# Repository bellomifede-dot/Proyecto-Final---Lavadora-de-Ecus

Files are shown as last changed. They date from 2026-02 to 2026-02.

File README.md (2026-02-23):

# Proyecto SCARA + Lavadora de ECUs

**Célula automatizada para la limpieza y manejo de Unidades de Control Electrónico (ECU)**

Este proyecto desarrolla una célula automatizada capaz de localizar, manipular y limpiar placas electrónicas (ECUs) mediante un robot SCARA y una unidad de lavado. El sistema busca reducir la intervención manual, homogeneizar el proceso y mejorar la trazabilidad de las piezas sometidas a mantenimiento o preparación previa a ensayos. 

<p align="center">
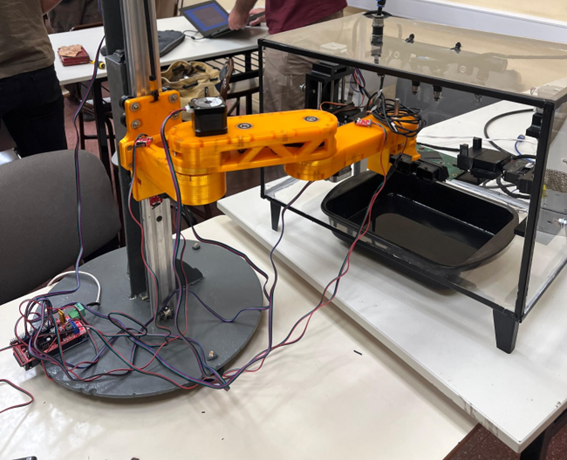
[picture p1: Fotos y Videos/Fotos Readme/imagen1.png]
Placa ECU - vista
  
</p>

---
## Tabla de contenidos
- [Descripción](#descripción)
- [Objetivos](#objetivos)
- [Funcionamiento general](#funcionamiento-general)
- [Componentes principales](#componentes-principales)
---

## Descripción
El sistema consiste en una mesa de entrada donde se colocan las placas sucias, un subsistema de visión que localiza cada placa, un robot SCARA que las recoge y entrega a una caja de lavado. La caja realiza dos etapas: un rociado dirigido (para despegar suciedad superficial) y una inmersión demostrativa en una bandeja. Al finalizar, la placa se devuelve al punto de salida lista para inspección o uso. 

## Objetivos
- Automatizar la manipulación y limpieza de ECUs.
- Minimizar el manejo manual y la exposición del operario a solventes.
- Homogeneizar el proceso para asegurar repetibilidad y trazabilidad.
- Proveer una base técnica y documental para reproducir o adaptar la célula en otros entornos.

## Funcionamiento general
1. **Detección**: la cámara ubica las placas en la mesa mediante algoritmos de visión por computador.  
2. **Clasificación / Etiquetado (opcional)**: identificación del tipo de ECU y registro.  
3. **Agarre y transporte**: el robot SCARA toma la placa y la coloca en la estación de lavado.  
4. **Lavado en dos etapas**:
   - Rociado dirigido (elimina suciedad superficial).
   - Inmersión demostrativa en bandeja de limpieza.  
5. **Devolución**: la placa vuelve al puesto de salida para inspección y trazabilidad.

## Componentes principales
- **Robot SCARA** — para recogida y manipulación precisa.  
- **Subsistema de visión** — detección y posicionamiento.  
- **Caja de lavado** — sistema de rociado + inmersión.  
- **Controlador / PC maestro** — coordina visión, robot y secuencia de lavado.  
- **ECUs** — piezas a limpiar; sensibles a humedad/solventes y por tanto se deben seguir consideraciones de seguridad.

<p align="center">
  <a href="https://youtu.be/JoXS6hfcZ1g" target="_blank" rel="noopener noreferrer">
    Demo - Lavadora de ECUs
  </a>
</p>

<p align="center"><em>Ver demo: Lavadora de ECUs</em></p>

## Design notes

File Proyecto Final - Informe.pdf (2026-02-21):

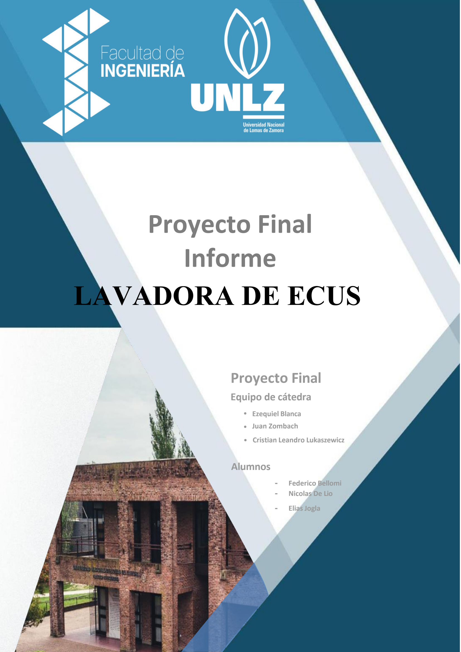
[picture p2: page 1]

Universidad Nacional de Lomas de Zamora

Facultad de Ingeniería

1

# Proyecto Final Informe

# LAVADORA DE ECUS

# Proyecto Final

## Equipo de cátedra

- Ezequiel Blanca
- Juan Zombach
- Cristian Leandro Lukaszewicz

## Alumnos

- Federico Bellomi
- Nicolas De Lio
- EliasJogla

Contenido

### 4. Diseño mecánico del Robot SCARA — (fase de diseño: cálculos previsionales)16

4.13 Fijación de la última polea al siguiente segmento (interfaz de transmisión entre segmentos)

La PC actúa como maestro: toma decisiones de alto nivel (qué pieza procesar, cuándo iniciar

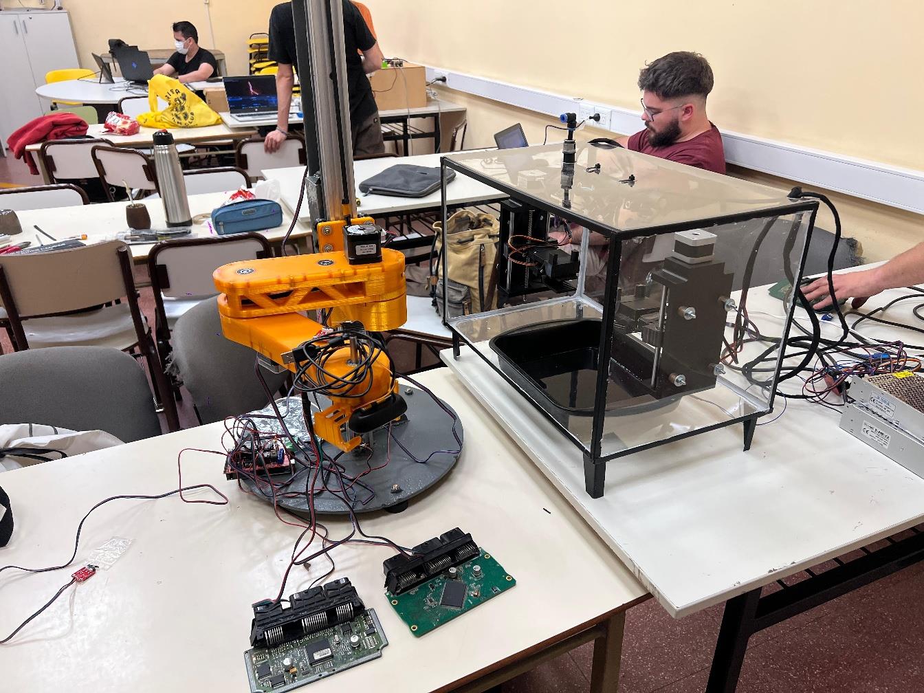
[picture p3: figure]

### 1. Introducción

En el ámbito de la electrónica automotriz moderna, las Unidades de Control Electrónico (ECU, Electronic Control Unit) cumplen un rol fundamental en la gestión de los sistemas del vehículo, tales como la inyección de combustible, encendido, control de emisiones y monitoreo de sensores críticos. Estas unidades están compuestas por placas electrónicas de alta densidad, con componentes sensibles a factores ambientales como la humedad, el polvo, residuos químicos y contaminantes atmosféricos.

Uno de los problemas más frecuentes en el sector de reparación electrónica automotriz es el deterioro progresivo de las ECUs debido a la acumulación de suciedad y a la presencia de humedad. Esta situación puede generar desde fallas intermitentes hasta la inutilización completa del sistema, provocando pérdidas económicas significativas y tiempos prolongados de diagnóstico y reparación. Los métodos de limpieza actualmente utilizados (principalmente el cepillado manual con alcohol isopropílico y el lavado por ultrasonido convencional) presentan limitaciones en términos de repetibilidad, eficiencia, estandarización y seguridad del proceso.

En este contexto, surge la necesidad de desarrollar una solución automatizada que permita mejorar la calidad del proceso de limpieza, reducir la intervención humana y aumentar la confiabilidad del procedimiento. El presente proyecto propone el diseño y desarrollo de una célula automatizada compuesta por un robot tipo SCARA y una lavadora de ECUs de doble etapa (aspersión controlada y limpieza ultrasónica), integrada con un sistema de visión artificial basado en inteligencia artificial para la detección y localización automática de las placas electrónicas.

La solución desarrollada contempla no solo la automatización del proceso de limpieza, sino también la integración coordinada entre los subsistemas mecánicos, electrónicos y de control, garantizando precisión en la manipulación, repetibilidad en los movimientos y seguridad en la operación. El robot SCARA se encarga de la manipulación de las placas mediante un sistema pick and place, mientras que la lavadora ejecuta el ciclo de limpieza de manera autónoma. El sistema de visión permite identificar la posición de las ECUs en el área de trabajo, transformando la información visual en coordenadas utilizables por el robot.

El desarrollo del proyecto implicó el diseño mecánico estructural del robot, el dimensionamiento de motores y fuentes de alimentación, el análisis de esfuerzos y torques, el diseño electrónico de potencia y control, la programación del microcontrolador, la implementación de algoritmos de cinemática inversa y la integración con un sistema de procesamiento de imágenes en una computadora externa.
El presente informe describe de manera detallada el proceso de diseño, cálculo, implementación y validación del sistema completo, incluyendo los análisis mecánicos y electrónicos correspondientes, la planificación del proyecto, la evaluación económica y los ensayos realizados para verificar el cumplimiento de los objetivos establecidos.

### 1.1 Contexto del problema

La evolución de la industria automotriz ha incrementado significativamente la cantidad y complejidad de sistemas electrónicos presentes en los vehículos modernos. Las Unidades de Control Electrónico (ECUs) son responsables de procesar señales provenientes de múltiples sensores y ejecutar estrategias de control en tiempo real, convirtiéndose en elementos críticos para el correcto funcionamiento del vehículo. Debido a su ubicación dentro del compartimiento del motor o en zonas expuestas a condiciones adversas, las ECUs se encuentran sometidas a variaciones térmicas, vibraciones mecánicas, humedad ambiental y posibles filtraciones de líquidos. Con el paso del tiempo, estas condiciones pueden generar acumulación de suciedad, corrosión en pistas conductoras y degradación de contactos eléctricos, afectando el desempeño del sistema.

En el ámbito de la reparación electrónica automotriz, la limpieza de estas placas constituye una etapa previa fundamental antes de realizar diagnósticos o intervenciones más profundas. Sin embargo, los procedimientos actuales presentan limitaciones importantes. La limpieza manual mediante cepillado y solventes depende en gran medida de la habilidad del operario, carece de repetibilidad y puede resultar insuficiente para remover contaminantes en zonas de difícil acceso. Por otro lado, los sistemas de lavado ultrasónico disponibles comercialmente no siempre están integrados dentro de un proceso automatizado que contemple manipulación, posicionamiento y control del flujo de trabajo.

Esta situación evidencia una oportunidad de mejora mediante la implementación de soluciones automatizadas que integren tecnologías de manipulación robótica, limpieza controlada y visión artificial, permitiendo estandarizar el proceso, aumentar la eficiencia y reducir la intervención humana directa.

### 1.2 Justificación técnica

El desarrollo de una célula automatizada para la limpieza de ECUs se justifica desde múltiples perspectivas técnicas y operativas. En primer lugar, la automatización del proceso permite garantizar condiciones de operación repetibles y controladas, reduciendo la variabilidad asociada al trabajo manual. Esto resulta especialmente relevante en tareas donde la precisión y el cuidado del componente son fundamentales para evitar daños adicionales.

Desde el punto de vista mecánico, la incorporación de un robot tipo SCARA ofrece ventajas significativas en aplicaciones de manipulación plana, debido a su estructura rígida en el eje vertical y su alta velocidad en movimientos en el plano XY. Estas características lo convierten en una solución adecuada para operaciones de tipo pick and place, como la carga y descarga de placas electrónicas en la lavadora.

En el aspecto electrónico y de control, el diseño integral del sistema permite dimensionar adecuadamente fuentes de alimentación, drivers de motores y protecciones eléctricas, asegurando un funcionamiento seguro y eficiente. Asimismo, la implementación de cinemática inversa y secuencias de homing contribuye a mejorar la precisión y confiabilidad del robot.

Por otra parte, la incorporación de un sistema de visión artificial basado en inteligencia artificial permite automatizar la detección y localización de las placas dentro del área de trabajo, eliminando la necesidad de posicionamiento manual previo y aumentando el grado de autonomía del sistema.

Finalmente, desde una perspectiva académica y de ingeniería, el proyecto integra conocimientos de diseño mecánico, electrónica de potencia, control, programación, procesamiento de imágenes e integración de sistemas, constituyendo una aplicación multidisciplinaria que refleja las competencias adquiridas durante la carrera de Ingeniería Mecatrónica.

### 1.3 Objetivo general

Diseñar, desarrollar e integrar una célula automatizada compuesta por un robot tipo SCARA, una lavadora de ECUs de doble etapa (aspersión controlada y limpieza ultrasónica) y un sistema de visión artificial basado en inteligencia artificial, con el propósito de optimizar el proceso de limpieza de placas electrónicas automotrices, garantizando precisión, repetibilidad, seguridad y reducción de la intervención humana.

### 1.4 Objetivos específicos

Para alcanzar el objetivo general planteado, se establecen los siguientes objetivos específicos:

- Diseñar y construir un robot tipo SCARA capaz de realizar movimientos en el plano XY con un eje vertical Z, logrando una repetibilidad mínima de 1 mm y capacidad de manipulación de cargas de al menos 100 g.
- Implementar el modelado matemático del robot, incluyendo el desarrollo de la cinemática directa e inversa, para permitir el posicionamiento preciso del efector final.
- Diseñar un sistema de gripper adecuado para la sujeción segura de placas electrónicas, considerando su geometría y fragilidad.
- Desarrollar una lavadora de ECUs que integre un sistema de aspersión controlada mediante alcohol isopropílico y un sistema de limpieza ultrasónica, garantizando la eliminación de contaminantes superficiales y profundos.
- Dimensionar y diseñar el sistema electrónico completo, incluyendo selección de motores, drivers, fuentes de alimentación, sensores de fin de carrera y protecciones eléctricas, realizando los cálculos correspondientes de corriente, potencia y disipación térmica.
- Implementar un sistema de visión artificial capaz de detectar y localizar automáticamente las placas electrónicas dentro del área de trabajo, utilizando un modelo de inteligencia artificial ejecutado en una computadora externa.
- Desarrollar la comunicación entre la PC y el microcontrolador del robot, permitiendo la transferencia de coordenadas procesadas por el sistema de visión.
- Integrar todos los subsistemas mecánicos, electrónicos y de control en una arquitectura coordinada que permita un funcionamiento autónomo del proceso completo.
- Realizar ensayos de validación para verificar el cumplimiento de los requisitos de repetibilidad, carga, limpieza e integración del sistema.

### 2. Marco teórico

### 2.1 Limpieza de placas electrónicas

2.1.1 Métodos tradicionales
La limpieza de placas electrónicas se realiza habitualmente mediante tres enfoques: limpieza manual con solventes, aspersión controlada y ultrasonido. La limpieza manual con alcohol isopropílico u otros disolventes es económica y efectiva para contaminantes superficiales, pero depende altamente de la pericia del operador y carece de reproducibilidad. La aspersión controlada aplica energía mecánica puntual mediante chorros de fluido para desalojar residuos adheridos, siendo una alternativa intermedia entre el tratamiento manual y la inmersión completa. La limpieza por ultrasonido actúa a escala microscópica por cavitación, permitiendo la remoción en zonas inaccesibles para las técnicas anteriores; requiere control de frecuencia, potencia y temperatura del baño.

Cada técnica tiene ventajas y limitaciones en términos de agresividad, compatibilidad con componentes, seguridad (especialmente si se emplean solventes inflamables) y repetibilidad. Para procesos industriales y estandarizados se recomiendan soluciones automatizadas que combinen etapas complementarias (por ejemplo, aspersión seguida de ultrasonido) para maximizar eficacia sin dañar los componentes.

2.1.2 Limpieza por aspersión (aplicación al prototipo)
La etapa de aspersión en el sistema propuesto utiliza inyectores de combustión montados en posición fija y una bomba con presión operativa entre 2.7 y 4.1 bar, rango típico de bombas de inyectores y suficiente para generar chorros con alta energía cinética. Los parámetros operativos relevantes que condicionan la eficacia son: presión de trabajo, caudal, diámetro y geometría de la tobera, distancia nozzle–superficie, ángulo de incidencia y tiempo de exposición.

En la práctica del prototipo, la pieza (ECU) se somete a un ciclo de rotación que expone sucesivamente cara superior e inferior a los chorros. Esta estrategia permite que boquillas fijas cubran ambas caras sin necesidad de mecanismos articulados adicionales para las boquillas, reduciendo complejidad mecánica y puntos de fallo.

2.1.3 Limpieza por ultrasonido (principios y estado del prototipo)
La limpieza por ultrasonido convierte energía eléctrica en ondas mecánicas en el líquido mediante transductores; las oscilaciones inducen cavitación y el colapso de microburbujas genera micro chorros que desprenden contaminantes. Los parámetros críticos son la frecuencia (normalmente 20–400 kHz), la potencia específica (W/L), el tiempo de exposición y la temperatura del baño. Frecuencias bajas (20–40 kHz) favorecen cavitación intensa para suciedad gruesa; frecuencias altas (≥100 kHz) producen limpieza más fina y suave.

En el prototipo actual existe una batea y un motor desbalanceado que, en su configuración, sirve como demostrador mecánico, pero no logra la excitación a frecuencias ultrasónicas efectivas. La implementación plena del ultrasonido requiere transductores piezoeléctricos y drivers apropiados. Además, el uso de ultrasonido en presencia de solventes inflamables requiere equipamiento certificado (ATEX u homologaciones equivalentes), ventilación y control térmico.

### 2.2 Robots SCARA

2.2.1 Arquitectura y propiedades esenciales
Un robot tipo SCARA (Selective Compliance Assembly Robot Arm) es un manipulador caracterizado por articulaciones rotacionales en el plano XY y un grado de libertad prismático o rotacional en el eje Z. Su rigidez en la dirección vertical, la alta velocidad y la precisión en el plano horizontal lo hacen especialmente apto para tareas de pick & place, inserción y manipulación de piezas planas. Para la manipulación de ECUs (componentes relativamente planos y frágiles) el SCARA combina buena velocidad de ciclo con suficiente rigidez y repetibilidad.

2.2.2 Selección para la aplicación de limpieza de ECUs
La elección del SCARA se fundamenta en la necesidad de integrar un sistema de manipulación que realice carga/descarga, posicionamiento frente a boquillas de aspersión y colocación en la batea ultrasónica, todo con mínimo contacto humano. Se valora además la posibilidad de integrar un efector con cámara (eye-in-hand) para detección y sujeción precisa.

### 2.3 Cinemática de robots SCARA

2.3.1 Notación y parámetros geométricos del prototipo
Denotamos L1 y L2 las longitudes de los dos eslabones en el plano XY; en el prototipo L1=160 y L2=200m. Las variables articulares son θ1 (theta 1) y θ2 (theta 2) que son rotaciones en las uniones base → eslabón 1 y eslabón 1 → eslabón 2) y z para el eje prismático.

2.3.2 Cinemática directa
Las expresiones de la cinemática directa permiten calcular la posición cartesiana (x,y,z) del efector en función de los ángulos articulares:

x = L1 cos(θ1

) + L2 cos (θ1 + θ2)
y = L1 sin(θ1

) + L2 sin (θ1 + θ2)
z = z

Estas relaciones son la base para establecer la transformación entre espacio articular y espacio cartesiano usada por el planificador del robot.

2.3.3 Cinemática inversa
Dada la posición (x,y) deseada del efector, la obtención de θ1 y θ2 se realiza mediante:

r

2 = x

2 + y

2
; cos(θ2

) =

r

2 − L1

2 − L2

2
2L1

2L2

2

;

y
θ2 = atan2 (±√1 − cos²(θ2
) , cos(θ2

))
θ1 = atan2(y, x) − atan2(L2 sin(θ2

) , L1 + L2cos (θ2))

La solución presenta ambigüedad de configuración (dos soluciones—elbow-up/elbow-down) que debe resolverse con criterios basados en límites mecánicos, obstáculos y eficiencia de la trayectoria.

2.3.4 Jacobiano y control de velocidad
El Jacobiano J(θ) relaciona velocidades articulares θ˙ con velocidades cartesianas p˙=[x˙ y˙]T mediante p˙=J(θ). La inversa del Jacobiano (cuando existe) se usa para convertir velocidades cartesianas deseadas en velocidades articulares necesarias. El determinante de J indica singularidades donde la manipulación es problemática; por tanto es esencial planificar trayectorias evitando configuraciones cercanas a dichas singularidades.

2.3.5 Workspace y limitaciones prácticas
El workspace teórico del SCARA en el plano XY viene dado por el conjunto de radios r tales que ∣L1−L2∣ ≤ r ≤ L1+L2 . En la práctica, las limitaciones mecánicas (topes físicos, interferencias de estructura, rango del efector, espacio de montaje) reducen el workspace útil. Adicionalmente, la interacción con el sistema de visión y la disposición de la lavadora fijan zonas operativas preferentes.

### 2.4 Sistemas de visión artificial

2.4.1 Objetivo funcional en el sistema
El sistema de visión tiene por objetivo detectar la presencia y estimar la pose (posición y orientación plana) de las ECUs sobre la mesa de trabajo para proporcionar coordenadas que el controlador del robot utilice para el pick & place. La solución en el prototipo combina detección por redes convolucionales y marcadores QR para robustez y precisión.

2.4.2 Pipeline de procesamiento propuesto

El flujo típico se compone de:

1. Adquisición: la cámara montada en el efector (eye-in-hand) captura imágenes. En el prototipo se usa una cámara comercial de consumo (Logitech C270 HD 720p), adecuada para demostración; su obturador y tasa de frames deben ser consideradas al programar movimientos.
2. Preprocesado: corrección de distorsión, filtrado y normalización del histograma para robustecer la detección ante variaciones de iluminación.
3. Detección/segmentación: empleo de un detector de objetos basado en CNN (por ejemplo YOLO u arquitecturas análogas) para obtener cajas delimitadoras y puntos claves.
4. Estimación de pose: uso de marcadores QR (uno fijo como referencia y uno variable en cada ECU) para obtener la transformación relativa ECU→referencia; concebir la estimación mediante homografía si el plano es conocido o mediante PnP en caso de tener referencias 3D.
5. Transformación a coordenadas del robot: mediante calibración hand–eye convertir la pose en coordenadas del robot y enviar comandos de posicionamiento.

2.4.3 Calibración cámara–robot y conversión píxel→mundo
Se distinguen dos calibraciones necesarias:
- Calibración intrínseca: determina parámetros de la cámara (fx, fy, cx, cy) coeficientes de distorsión radial/tangencial. Se obtiene típicamente con patrones planos (tablero de ajedrez) y librerías como OpenCV.
- Calibración extrínseca / hand–eye: define la transformación rígida entre la cámara y la herramienta (efector). En configuraciones eye-in-hand es indispensable para traducir observaciones de la cámara a movimientos del robot

con precisión.

Si la cámara observa esencialmente un plano de trabajo fijo y la altura no varía significativamente, una homografía 2D proporciona una conversión eficaz entre coordenadas de imagen y coordenadas del plano. En casos más generales será necesario estimar la pose 3D usando solvePnP y la transformación hand–eye.

### 2.5 Microcontroladores y control de motores paso a paso

2.5.1 Plataforma de control y arquitectura electrónica

La electrónica de control del prototipo se basa en un microcontrolador de arquitectura compatible con proyectos de control de múltiples motores (se utiliza la placa Arduino Mega sobre la que se monta una shield tipo RAMPS 1.4 para alojar drivers de potencia). Esta configuración facilita la integración de drivers tipo DRV8825, sensores I²C (multiplexor TCA9548A y AS5600) y finales de carrera.

2.5.2 Principios de motores paso a paso y dimensionamiento aplicado
Los motores paso a paso se caracterizan por su paso por revolución (200 pasos = 1,8°), torque de retención y curva de torque a velocidad. En el proyecto se emplean NEMA17 de alto torque con especificación nominal 4.3 kg·cm (≈ 0.4217 N·m) y un NEMA17 pancake para J6 con 1.6 kg·cm (≈ 0.1569 N·m).

Efecto de la reducción: las transmisiones implantadas (relación compuesta 16:1 en J1/J2 y 1:5 en J6) multiplican el torque disponible en la salida de la transmisión, mientras que disminuyen la velocidad y aumentan la resolución angular por paso. Aplicando la reducción 16:1 al motor de 0.4217 N·m, el torque teórico disponible en el eje de salida es ≈ 6.747 N·m, una magnitud que excede holgadamente la demanda gravitatoria de una ECU de 0.1 kg colocada a r = 0.36 m (τ ≈ 0.353 N·m). Para dimensionamiento dinámico se debe incluir el término de inercia I y la aceleración angular requerida:

α: τ = Iα + τgravedad + τfricción

2.5.3 Drivers de etapa de potencia y ajustes térmicos

Los DRV8825 regulan corriente mediante control por chopper y requieren ajuste del límite de corriente acorde al motor. La disipación térmica es significativa; es imprescindible disipadores y ventilación forzada. Ajustar la corriente máxima evita sobrecalentamiento de los drivers y limita la corriente RMS en los motores.

2.5.4 Dimensionamiento de la fuente de alimentación (cálculo aplicado)

Con los consumos nominales aportados se calcula:
- Motores: 3 × NEMA17 alto-torque a 1.7 A/fase (3×1.7 = 5.1 A) y 1 × pancake a 1.0 A → total motores = 6.1 A.
- Aplicando margen de seguridad del 30%: corriente de diseño ≈ 7.93 A.
- Potencia requerida a 12 V: P=12 V×7.93 A≈95.2

La elección de una fuente 12 V / 15 A ofrece margen suficiente para picos de corriente y expansión futura. El circuito de control (Arduino, multiplexor I²C, sensores y drivers de lógica) se alimenta desde USB de la PC; el consumo estimado total de la electrónica de control es ≈ 174 mA (con margen operativo tomado a 250 mA).

### 3. Descripción general del sistema

### 3.1 Visión general y propósito

La célula automatizada integra un manipulador tipo SCARA, una lavadora de ECUs de doble etapa (aspersión y batea) y un sistema de visión montado en el efector del robot. El objetivo es automatizar la carga, limpieza y descarga de placas electrónicas automotrices con repetibilidad y mínima intervención humana. Las ECUs que se procesan disponen previamente de una pieza adaptadora impresa en 3D que incorpora un marcador QR y ranuras autocentrantes para el gripper del robot, estandarizando la sujeción y la referencia visual.

### 3.2 Arquitectura funcional (diagrama lógico — descripción)

La arquitectura se organiza en cuatro subsistemas principales:
- Operador / bandeja inicial. El operario inserta la pata 3D en la ECU y deja las piezas en la mesa de trabajo dentro del alcance del SCARA.
- Visión y procesamiento (PC). La cámara del efector captura imágenes; la PC ejecuta el detector y el módulo de IA para localizar QRs y calcular poses. (Se utiliza una cámara comercial Logitech C270 para la etapa de demostración). Logitech
- Control SCARA. Control local del manipulador (motor drivers, encoders, firmware) basado en una placa Arduino Mega con shield RAMPS 1.4. Arduino
- Lavadora (control local). Control independiente basado en otro Arduino Mega que gestiona bombas, servos, guías lineales y la batea; la comunicación simple entre SCARA y lavadora se realiza vía ESP32 para señales de evento.

El flujo de información es: PC (visión) → Control maestro → Control SCARA → (ESP32) → Control Lavadora, con señales de estado de retorno desde la lavadora hacia el maestro.

### 3.3 Flujo operativo (secuencia funcional, paso a paso)

1. Preparación: el operario instala la pata 3D en cada ECU y las deja sobre la mesa.
2. Inicio: el operario pulsa “Play” en la interfaz de la PC para iniciar la rutina.
3. Escaneo: el SCARA recorre posiciones de escaneo; la cámara captura imágenes y la PC detecta QRs.
4. Selección: al detectar un QR válido, la PC manda la pose al SCARA.
5. Pick: el SCARA va a la posición de captura, activa el gripper y toma la pieza (la geometría autocentrante asegura sujeción con tolerancia).
6. Transferencia: el SCARA lleva la pieza a la zona de entrega de la lavadora y deposita la ECU en la posición de transferencia.
7. Cedencia: el SCARA envía señal (ESP32 → Arduino Lavadora) indicando “pieza colocada”; la lavadora cierra sus grippers internos y confirma la sujeción; el SCARA se retira.
8. Lavado: la lavadora ejecuta la secuencia preconfigurada: aspersión cara A, rotación (≲180°), aspersión cara B, inmersión en batea.
9. Fin de ciclo: al completar el ciclo, la lavadora abre sus grippers y envía señal de “listo” al SCARA; el SCARA recoge la ECU y la deposita en la posición de salida.
10. Repetición/Finalización: el SCARA reanuda el escaneo. Si no detecta más piezas tras recorrer todas las zonas, finaliza la rutina.

### 3.4 Layout físico y dimensiones principales

- Lavadora (caja): altura del cuerpo = 33 cm; patas = 7 cm → altura total ≈ 40 cm; ancho = 53 cm; profundidad = 33 cm.
- Separación robot–lavadora: ≈ 360 mm entre el centro de trabajo del robot y la abertura de la lavadora, distancia calculada para que el gripper realice la transferencia sin interferencias.
- Carcasa y visibilidad: las cuatro paredes laterales son acrílico; el frente del prototipo está abierto (sin puerta). La estructura principal es chapa doblada en L para rigidez.
- Montaje: actualmente la célula se apoya en patas; se recomienda anclaje al piso para mitigar vibraciones y garantizar repetibilidad.

### 3.5 Descripción funcional de la lavadora

Estructura y componentes internos: la lavadora es un cubo rectangular con la cara frontal abierta. Internamente incorpora:
- Pinzas internas y guías verticales: dos mecanismos verticales con 2 × NEMA17 (tornillo + guía lineal) para ascenso/descenso de los conjuntos de pinzas; finales de carrera implementados para homing y límites.
- Servomotores: 4 × MG90 (dos por lado): uno para rotación en Y (voltear la pieza) y otro para cerrar/abrir los grippers.
- Inyectores fijos en techo: inyectores de nafta reales conectados a una bomba ON/OFF que entrega 2.7–4.1 bar; las boquillas están fijas, la placa se rota para exponer ambas caras.
- Batea de base: recoge líquidos y sirve de zona de inmersión; en prototipo la batea no integra transductores ultrasónicos activos (solo demostrador mecánico).

### 3.6 Mecanismo de sujeción y gripper

- Gripper del SCARA: impreso en PETG, apertura máxima 50 mm; ranura de entrada 38 mm. La pata 3D contiene un perfil autocentrante (vista frontal: rectángulo sobre trapecio que forma un cono guía) que asegura centrado y captura aun con desvíos de unos milímetros.
- Interfaz de entrega: el SCARA deposita la ECU en la zona de transferencia y notifica via ESP32 al Arduino de la lavadora; la lavadora cierra sus pinzas internas y confirma antes de iniciar el ciclo. No se usan sensores de fuerza; la geometría mecánica realiza la función de alineado y sujeción.

### 3.7 Electrónica, alimentación y comunicaciones

- Subsistemas electrónicos: SCARA y Lavadora disponen cada uno de una placa Arduino Mega + RAMPS 1.4 para drivers y sensores; el SCARA alimenta su lógica desde la PC (USB) y desde una fuente 12 V/15 A para potencia. La Lavadora cuenta con fuentes independientes (12 V/20 A y 5 V/20 A).
- Comunicaciones: señalización simple entre SCARA y Lavadora por medio de un ESP32 (GPIOs / pin-level signaling). Actualmente no hay un protocolo de handshake formal; la interacción es basada en eventos discretos y retardos.

### 3.8 Tiempos de ciclo y parámetros de operación

- Visión / detección por zona: ≈ 30 s por zona de escaneo.
- Pick & place (captura + transferencia): ≈ 15 s.
- Ciclo de limpieza (configuración actual): ≈ 60 s total: 15 s aspersión cara A → rotación → 15 s aspersión cara B → inmersión 20 s en batea.
- Tiempo total típico por pieza: entre 1 min 30 s y 2 min (depende de detección, colas y tiempos de transferencia).

### BLOQUE I – ROBOT SCARA

### 4. Diseño mecánico del Robot SCARA — (fase de diseño: cálculos previsionales)

### 4.1 Objetivo

El objetivo de esta sección es presentar el análisis mecánico previsto en la fase de diseño, los supuestos de masa y geometría que se consideraron al dimensionar el manipulador, los cálculos de pares estáticos y dinámicos basados en esos supuestos, la resolución esperada y las verificaciones estructurales preliminares.

### 4.2 Supuestos de diseño (valores adoptados a efectos de cálculo)

Estos son los supuestos de diseño que se usarán para todos los cálculos de esta sección. Son intencionalmente conservadores para dar margen en la fase de proyecto:

- Geometría:
- L1=160 mm (brazo proximal, entre centros).
- L2=200 mm (brazo distal, entre centros).
- Alcance máximo: rmax = L1+L2 =0.360 m
- Masas (supuestas en diseño):
- Segundo segmento (brazo proximal): m2=0.70 kgm
- Tercer segmento (brazo distal): m3=0.50 kgm
- Efector (gripper + pieza adaptadora + ECU) supuesto: mg=0.10 kg (100 g).
- Material y fabricación: piezas impresas en PETG infill ≈ 50–60 %, paredes nominales ≈ 8 mm.
- Actuadores y transmisiones (selección de proyecto):
- Motores NEMA17 alto-torque con torque nominal
τm=4.3 kg⋅cm≈0.4217 N⋅m
- Relación de transmisión en J1/J2 tomada: i=16:1
- Motor J6 pancake y relación 1:5 (no se analiza en detalle aquí).
- Perfil de movimiento de referencia para dinámicas: giro de 90∘=π en T=0.5 con perfil triangular (acelera la mitad del tiempo y desacelera la otra mitad).

### 4.3 Cálculo estático de pares (fase de diseño)

4.3.1 Distancias de CG (modelo simple)
Asumimos centros de masa en mitad de cada eslabón: rm2 =

L1
2

=

0.160m
2

= 0.08 m

rm3 = L1 +

L2
2

= 0.160m + 0.100m = 0.260 m rmg = L1 + L2 = 0.360 m

4.3.2 Momento por gravedad en J1 (paso a paso)

Usamos los supuestos de masa del diseño.

1. Momento debido a m2=0.70 kg en rm2=0.080

Mm2 = m2 ⋅ g ⋅ rm2
Mm2 = 0.7 ⋅ 9.81 ⋅ 0.080
Mm2 = 0.54936 Nm
2. Momento debido a m3=0.50 kg en rm3=0.260 m:

Mm3 = m3 ⋅ g ⋅ rm3
Mm3 = 0.5 ⋅ 9.81 ⋅ 0.260
Mm3 = 1.2753 Nm
3. Momento debido a mg=0.10 kg en rg=0.360m:

Mg = mg ⋅ g ⋅ rg
Mg = 0.1 ⋅ 9.81 ⋅ 0.360
Mg = 0.35316 Nm
4. Momento total en J1 (estático, diseño):

MJ1 = Mg + Mm2 + Mm3
MJ1 = 0.35316 Nm + 0.54936 Nm + 1.2753 Nm MJ1 = 2.17782 Nm

4.3.3 Par disponible (diseño) y margen

- Par nominal motor: τm=0.4217 N⋅m
- Par disponible en salida tras i=16:1

τsalida = τm ⋅ i = 0.4217 ⋅ 16 = 6.7472 Nm

- Margen previsto:
Margen =

τsalida

MJ1

=

6.7472 Nm
2.17782 Nm = 3.1

Esto nos da un margen aproximado de 3 veces el torque necesario con respecto al torque producido por los motores (asumiendo que no hay perdida por fricción)

### 4.4 Estimación dinámica (fase de diseño)

4.4.1 Inercia equivalente (modelo puntual) — pasos y números

Aproximamos las masas como puntos en sus CG respecto a J1:

Im2 = m2 ⋅ rm2

2 = 0.7 ⋅ 0.08² = 0.00448 kg ⋅ m² Im3 = m3 ⋅ rm3

2 = 0.5 ⋅ 0.260² = 0.03380 kg ⋅ m² Ig = mg ⋅ rmg

2 = 0.1 ⋅ 0.360² = 0.01296 kg ⋅ m²

Suma (inercia total aproximada alrededor de J1):

IJ1 = Im2 + Im3 + Ig
IJ1 = 0.00448 kg ⋅ m² + 0.03380 kg ⋅ m² + 0.01296 kg ⋅ m² IJ1 = 0.05124 kg ⋅ m²

4.4.2 Aceleración de referencia y par dinámico

Para 90° en T=0.5 (perfil triangular) la aceleración angular máxima es

α =

4θ
T

2 =

4(π/2)
0.5

2 = 8π = 25.133 rad/s

2

Par dinámico requerido:

τdinámico = IJ1 ⋅ α = 0.05124 kg ⋅ m²

| ⋅ 25.133 rad/s 2 = 1.2878 Nm

4.4.3 Demanda total (dinámica + gravedad) en J1

τtotal requerido = MJ1 + τdinámico = 2.17782 Nm + 1.2878 Nm τtotal requerido = 3.46562Nm

En términos de par en el motor (antes de reducción):

τtotal requerido en motor =

τtotal requerido
16 = 0.2166 Nm

Comparación con torque motor nominal τm=0.4217 N⋅m → margen dinámico a nivel motor ≈ 1.94 (sin pérdidas).

### 4.5 Resolución esperada (fase de diseño)

- Paso motor: 200 pasos/rev → 1.8° por paso.
- Con reducción i=16:1 la resolución en articulación es de:

Δθart =

1.8°
16 = 0.1125° = 0.0019635 rad
- Desplazamiento lineal en extremo (r = 0.36 m) por paso:
Δs = 0.36m ⋅ 0.0019635 rad = 0.000707m = 0.707mm esto sitúa la resolución sin microstepping en ≈ 0.7 mm en el extremo.

### 4.6 Resumen numérico (valores previstos por diseño)

- Par estático previsto en J1:
MJ1 = 2.178 Nm
- Par dinámico previsto (90° en 0.5 s):
τdinamico = 1.288 Nm
- Demanda total prevista:

τtotal requerido = 3. 46562Nm

- Par disponible en salida (diseño):

τsalida = 6.7472 Nm

- Margen estático previsto ≈ 3.1; margen dinámico a nivel motor ≈ 1.94.
- Resolución por paso (sin microstepping): ≈ 0.1125° → ≈ 0.707 mm en el extremo.

### 4.7 Pilar / columna del eje Z — Base estructural y montaje

La columna principal del SCARA (figura 4.1) está construida a partir de un perfil UPN80 de acero de 74 cm de altura, soldado a una placa base circular de acero (Ø 400 mm, espesor 6 mm). La base incorpora tres orificios Ø 8 mm distribuidos a 120° para la fijación mediante tres regatones de goma que actúan como pies niveladores; las roscas en dichos orificios fueron soldadas para facilitar el montaje. Para refuerzo se añadieron dos nervios triangulares (catetos 70 mm) soldados a la cara externa de una de las alas del UPN, aportando rigidez a flexión en la parte inferior de la columna.

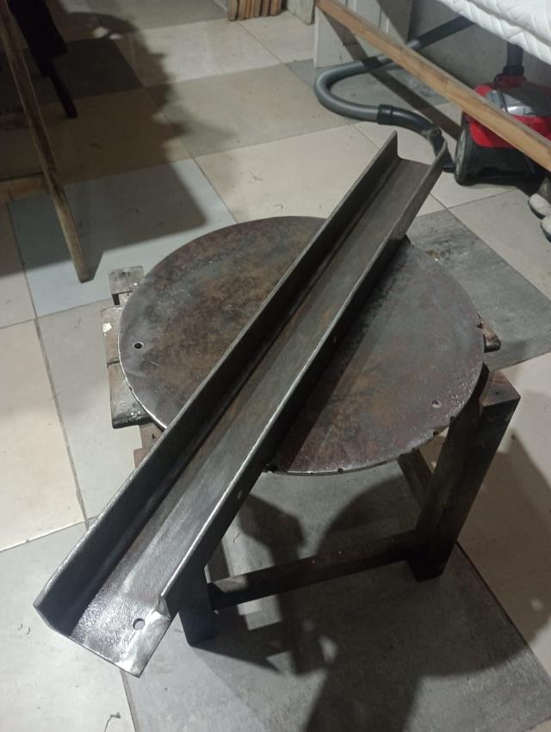
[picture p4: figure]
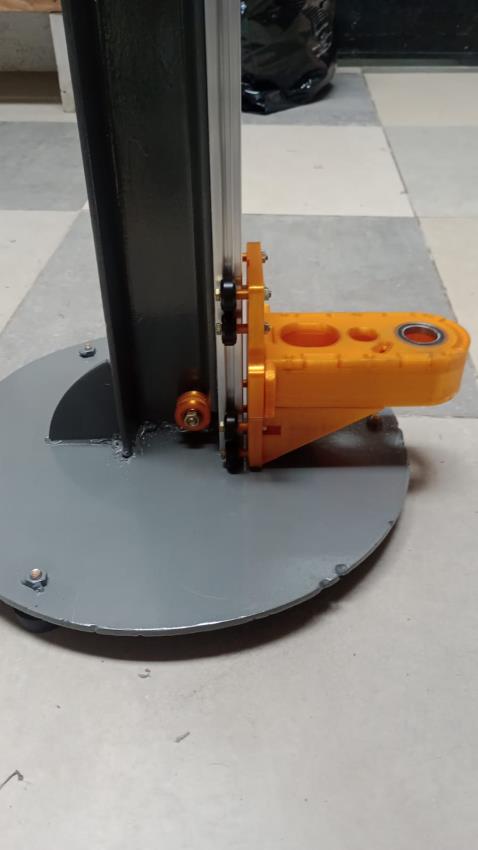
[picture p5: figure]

Figura 4.1 – Materiales para base del robot | Figura 4.2 – Guía lineal de aluminio + Vslots

Sobre una de las alas del UPN se fija mediante tornillos M6 avellanados un perfil de aluminio 2040. El perfil de aluminio 2040 actúa como guía de desplazamiento del carrito superior; en sus ranuras laterales se montan 8 V-slots fijados a un carro que soporta todo el conjunto SCARA. El apriete de la fijación se diseñó de modo que la cabeza de los bulones quede rasante en la cara exterior del 2040 y no sobresalga ni en la cara externa (para no realizar una interferencia con el carrito) ni en la cara interna del UPN (para no realizar una interferencia con el sistema de contrapeso).

La distancia entre la cara del perfil de aluminio (plano de montaje) y el centro del eje final del primer segmento es de 135 mm; esta cota se emplea en los cálculos de alcance.

### 4.8 Guía lineal del eje Z

La guía vertical que gobierna el eje Z (Figura 4.2) está implementada mediante el perfil de aluminio 2040 y 8 V-slots montados sobre un carro único. El carro incorpora el hospedaje para soportar el conjunto del SCARA y actúa como interfaz entre la columna y los segmentos rotatorios.

- Recorrido útil (stroke) del carro: ≈ 550 mm (recorrido funcional, dentro del eje total de 740 mm del perfil).
- Final de carrera / homing: el tope inferior está materializado por un micro-switch alojado en la parte baja del carro; al descender, éste hace tope contra la base circular y activa el final de carrera.

Este esquema aporta una solución simple y robusta: la combinación 2040 + V-slots con carro garantiza rigidez lateral suficiente para el sistema en las condiciones de trabajo previstas y facilita el montaje y regulación de la correa abierta que actúa como contrapeso.

### 4.9 Sistema de contrapeso del eje Z

El contrapeso definitivo se fijó en 2.4 kg (medido). El esquema de operación es el siguiente: en la parte superior del eje Z se aloja la caja reductora (1:5) cuyo eje final entrega potencia a una polea GT2. Desde esta polea parte una correa lineal que corre paralela al ala externa del UPN y va conectada a la parte superior del carro. La correa continua internamente dentro del UPN hasta la parte superior del contrapeso (alojado en el interior del perfil UPN) de modo que las alas del UPN actúan como guía para el contrapeso.
- Longitud de correa abierta (desde la punta superior del contrapeso hasta la punta superior del carro): ≈ 780 mm.
- Implementación: correa GT2 6 mm, correa abierta con punto de anclaje superior en contrapeso y superior en carro; la tensión se ajusta en el montaje.
Este diseño proporciona compensación de peso efectiva, reduciendo significativamente el par estático exigido al motor Z y permitiendo la transmisión 1:5 sin necesidad de un reductor excesivo.

Figura 4.3 – Sistema de contrapeso

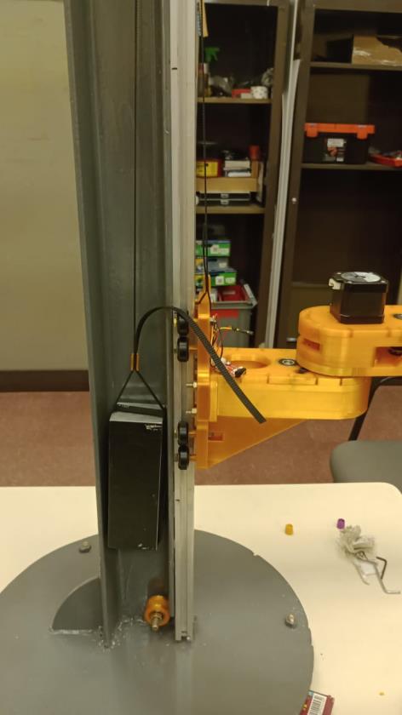
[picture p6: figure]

### 4.10 Fijación mediante perfil D (chaveta plana) del eje Z a la polea

En el eje de transmisión que une la salida del
reductor y la polea de extracción de correa se
emplea una solución de perfil plano (flat / “D”). Sobre un perno de posición Ø 8 mm se mecanizó una cara plana (flat) con anchura efectiva ≈ 6 mm, de forma que las poleas cuyo alojamiento están diseñadas con orificio en forma de “D” (Ø 5.9 mm sobre el plano) se ajustan por interferencia y transmiten torsión sin juego apreciable. Las poleas se fijan con tornillos prisioneros que inciden sobre la superficie plana, garantizando la transmisión requerida. Esta solución demuestra ser efectiva en la práctica y evita la necesidad de chavetas separadas.

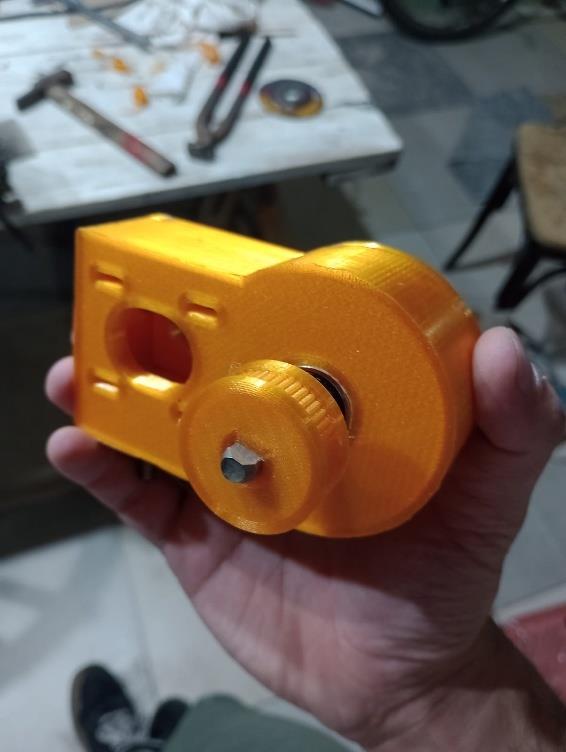
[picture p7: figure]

Figura 4.4 – Eje y Poleas perfil D

### 4.11 Poleas GT2 paramétricas y plantilla CAD

Todas las poleas utilizadas en el robot fueron generadas mediante una plantilla paramétrica en Autodesk Inventor. La plantilla incorpora las fórmulas estándar (pitch, número de dientes, diámetro primitivo, diámetro exterior y diámetros interiores) y permite variar el número de dientes para obtener automáticamente el diámetro correspondiente, manteniendo la compatibilidad con correa GT2 de 6 mm.

En el informe se documenta que las poleas están basadas en dicha plantilla paramétrica (Anexo 4.B contiene los .ipt y .stl exportados). Se refleja además la regla de diseño empleada: seleccionar número de dientes en el módulo GT2, este cambio de dientes dispara todos las demás variables.

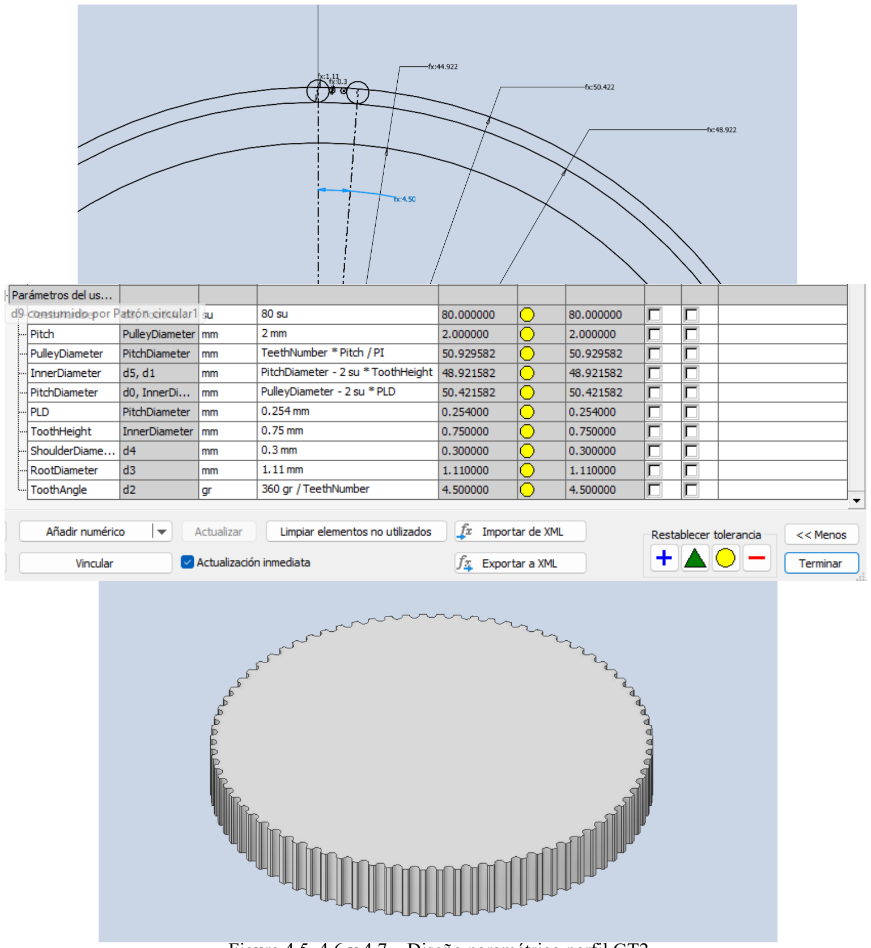
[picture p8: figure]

Figura 4.5, 4.6 y 4.7 – Diseño paramétrico perfil GT2

### 4.12 Mecanismos de transmisión por segmentos (resumen y descripción)

Se documentan a continuación los trenes de transmisión tal y como están implementados:

- Eje Z: mecanismo de 1 etapa (dos ejes). Polea del motor NEMA17: 16 dientes; polea del eje conducido: 80 dientes → relación 1:5. Ambos ejes participan en la transmisión (uno entrega potencia, el otro recoge) y la correa hacia el contrapeso se conecta en el eje de salida.
- Primer segmento (brazo proximal): mecanismo en 2 etapas (tres ejes).
- Eje motor: polea 16 dientes.
- Eje intermedio (loco) con polea doble: 80 dientes (inferior) y 25 dientes (superior).
- Eje final: polea 80 dientes.
- Relaciones: primera etapa 1:5 (80/16), segunda etapa 1:3.2 (80/25). Multiplicadas dan la reducción compuesta de 16:1.
- Segundo segmento (brazo distal): idéntico al primer segmento en topología: primera etapa 1:5 (80/16), segunda etapa 1:3.2 (80/25).
- Tercer segmento (efector): mecanismo de 1 etapa (dos ejes): motor polea 16 dientes, polea final 80 dientes → relación 1:5.

En las primeras etapas (donde se monta el NEMA17) los alojamientos para ajustar la posición del motor son ranuras alargadas con forma de chaveta para permitir el tensado de la correa al desplazar el motor y fijarlo con tornillos. En las segundas etapas se emplean idlers (poleas locas) para ajustar la corona de la correa: en el primer segmento el idler empuja la correa hacia adentro; en el segundo segmento la empuja hacia afuera, medidas que permiten un ajuste fino de la tensión y reducen deslizamientos.

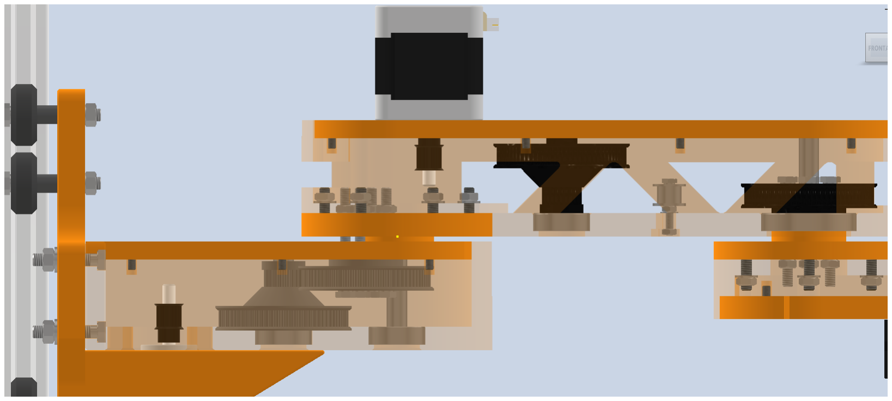
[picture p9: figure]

Figura 4.8 – Mecanismos de transmisión primer y segundo segmento

### 4.13 Fijación de la última polea al siguiente segmento (interfaz de transmisión entre

segmentos)
Para garantizar rigidez en la transmisión entre segmentos se emplea el siguiente esquema, probado en el prototipo:
- En el lado que transmite potencia se monta un cojinete 6805 (de mayor diámetro) y, en el extremo opuesto, un 625. La polea que transmite tiene un asiento interno que encaja alrededor del 6805. La polea dispone además de cuatro orificios radiales que permiten pasar tornillos M4 que la fijan mecánicamente al plano del siguiente segmento. Al apretar esos tornillos se comprime el cojinete 6805, lo que elimina cualquier juego entre la cara de la polea y la cara del segmento receptor. Este sistema crea una unión rígida sin necesidad de ejes pasantes adicionales y se usa en los puntos de transmisión al final del primer, segundo y tercer segmento.
- En el lado contrario a la transmisión (no conductor) se mantiene el rodamiento 625, que permite el apoyo radial sin transmitir torsión.

El paso de cables no se realiza a través de esta unión; todos los cables se canalizan por el exterior.

### 4.14 Pilar / soporte de unión entre segmentos

El soporte que sostiene el rodamiento y fija la polea está realizado con un eje de acero (perno de posición) que limita la desviación lateral. La fuerza de transmisión se realiza mediante la extensión interna de la polea que atraviesa el rodamiento y se fija con tornillos M4 al siguiente segmento. Debido al diseño de sujeción por compresión del cojinete, no se aprecia juego axial significativo y no han sido necesarios topes axiales adicionales en operación normal.

### 4.15 Shape Generator aplicado al segundo segmento

Se aplicó Shape Generator sobre el segundo segmento con objetivo principal de reducción de masa manteniendo rigidez frente a solicitaciones de flexión. Resumen del proceso y resultados:

- Restricciones y condiciones de contorno: se definió el empotramiento en la interfaz de sujeción al primer segmento (punto de anclaje superior), se preservaron zonas sólidas (rectángulo en la cara inferior para asegurar montaje y unión de rodamientos) y se conservaron los diámetros de los alojamientos de los rulemanes.
- Cargas aplicadas: se distribuyeron cargas que simulan el esfuerzo del motor superior (dividida en cuatro cargas de 0.002 MPa) y la carga transmitida en el eje distal (0.004 MPa), además de la gravedad.
- Objetivo: minimizar masa con restricción de espesor mínimo de pared en caras críticas (superior e inferior) para priorizar resistencia a la flexión.
- Resultados: se probaron topologías con reducción de masa al 20%, 30%, 40% y 50%; la variante seleccionada y fabricada fue la de ≈ 40% de reducción de masa, por ofrecer mejor balance entre rigidez y economía de material. A partir de la topología generada se diseñaron nervios triangulares y se mecanizó la pieza para obtener una geometría apropiada para impresión/maquinado.
- Implicaciones de fabricación: la topología final fue adaptada a las restricciones de impresión en PETG (orientación de capas y soportes) y mecanizado para los alojamientos de rulemanes. Resultados comparativos (masa original vs optimizada) y vistas CAD se adjuntan en Anexo 4.B.

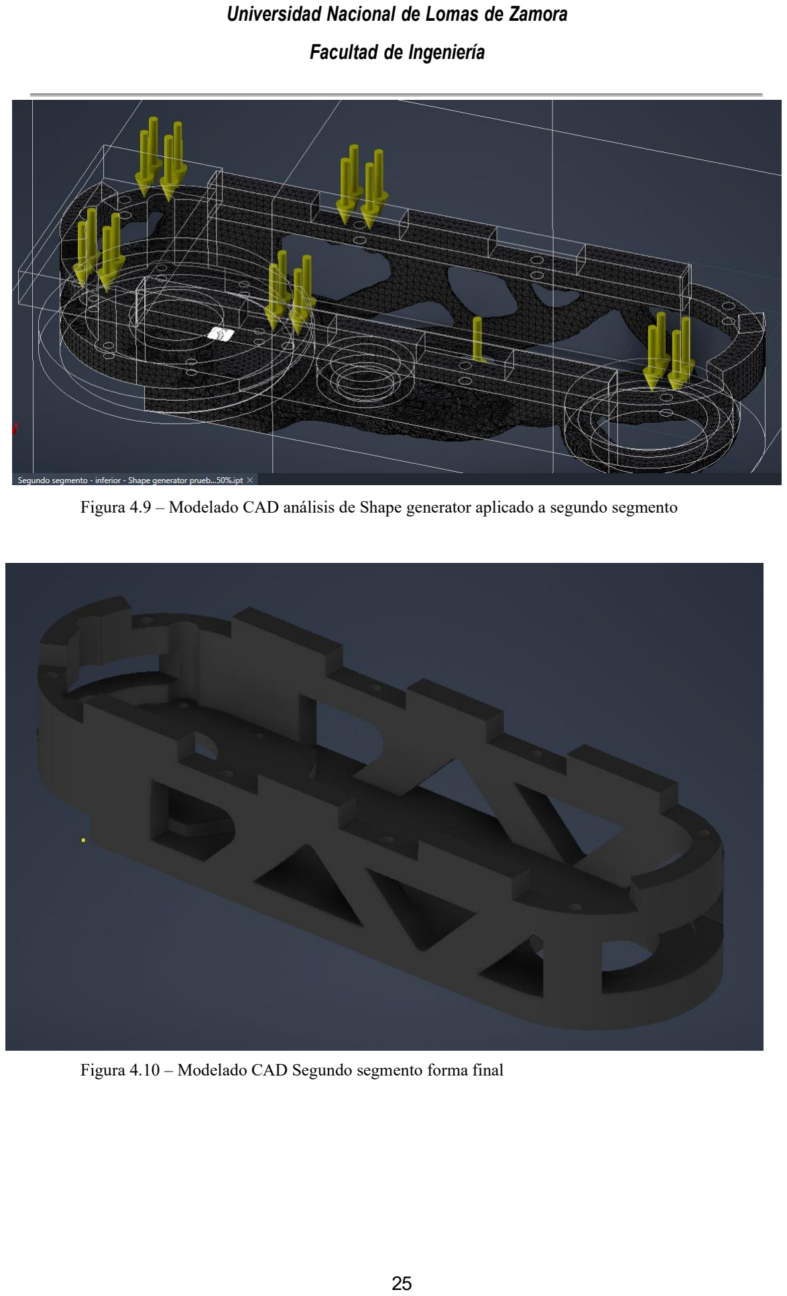
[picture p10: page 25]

Figura 4.9 – Modelado CAD análisis de Shape generator aplicado a segundo segmento

Figura 4.10 – Modelado CAD Segundo segmento forma final

### 4.16 Diseño del gripper y ranura de sujeción (interfaz con la pieza adaptadora)

El gripper está impreso en PETG y presenta las siguientes características principales:

- Apertura máxima 50 mm; ranura de entrada diseñada en 38 mm.
- Mecanismo de cierre con servo SG90 que actúa sobre un engranaje-cremallera: el servo acciona un piñón que transforma el giro en movimiento lineal de las garras.
- El efector incorpora alojamiento para la cámara y la electrónica del servo.
- La ranura de sujeción presenta un diseño autocentrante: vista en planta, la geometría combina un rectángulo sobre un trapecio cuyos flancos describen un cono guía que gradualmente centra la pieza al entrar; este perfil permite tolerancias de error de posicionamiento del orden de varios mm y asegura un centrado pasivo cuando el gripper cierra.
•
El diseño prioriza facilidad de montaje y repetibilidad: no se requieren sensores de fuerza para la toma salvo en casos extremos; el centrado geométrico es el mecanismo principal de alineado.

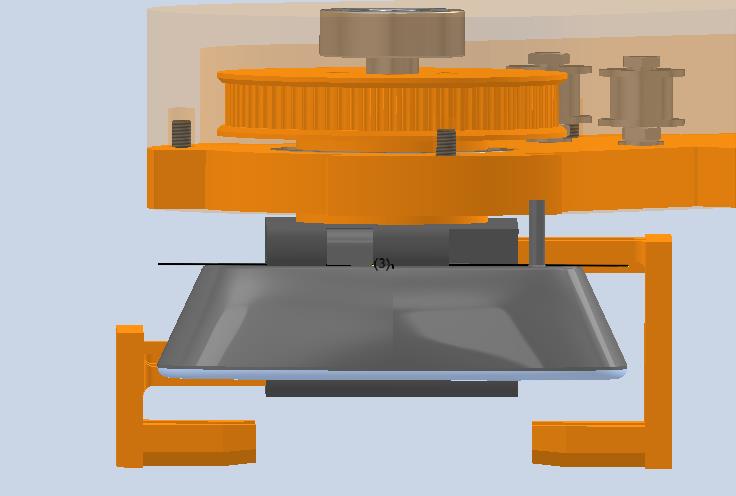
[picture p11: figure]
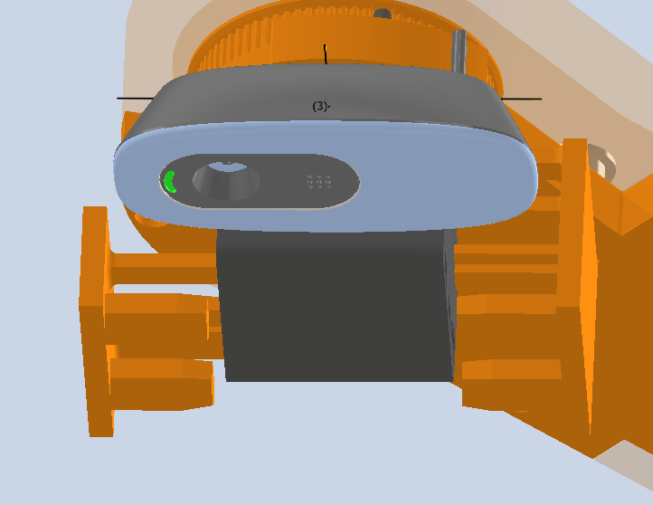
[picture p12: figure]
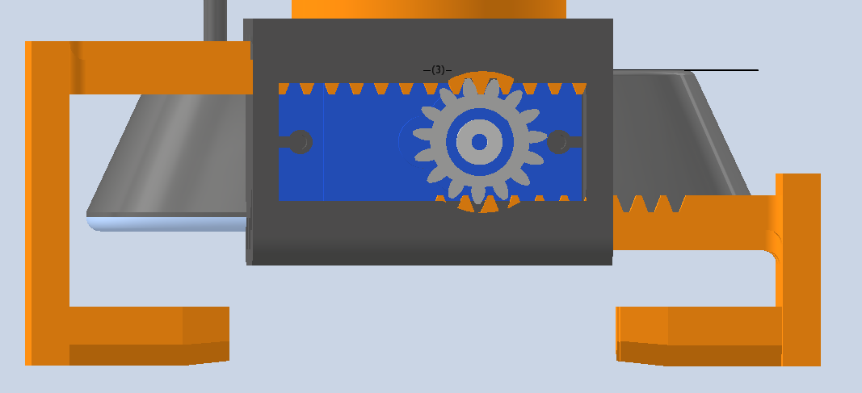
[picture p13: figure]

Figura 4.11, 4.12 y 4.13 – Gripper, vista frontal, vista en perspectiva, y vista trasera

### 4.17 Piezas críticas y consideraciones de tolerancia

Las piezas que requieren especial atención son las estructuras y tapas de cada segmento (primer, segundo y tercer segmento) ya que soportan las mayores solicitaciones. Si bien no se especifican tolerancias geométricas estrictas en todas las piezas, se debe prestar especial atención a:

- Alojamientos de rulemanes (625 y 6805): inspección de ajuste y concentricidad; asegurar que el asiento sea coaxial y el diámetro permita montaje sin deformaciones.
- Superficies de unión entre segmentos: comprobar planitud y perpendicularidad en montaje para evitar introducción de cargas axiales no deseadas.
- Perno de posición Ø 8 mm que actúa como eje: verificar que no presente run-out apreciable.
En el proceso de montaje se recomienda verificar el ajuste de los rulemanes y corregir con ligeros ajustamientos si se detecta juego.

### 4.18 Gestión de cableado y trazado mecánico

La gestión de cableado se implementa como un sistema en forma de “árbol” con ramales de distintos diámetros y con uso de cadena portacables tipo piel de serpiente:

- Diámetros empleados: 3 mm, 5 mm, 8 mm y 12 mm en los distintos tramos.
- Arquitectura: los tramos con pocos cables se usan con canal de 3 mm; al agruparse se pasa a 5 mm, 8 mm y finalmente al ramal principal de 12 mm que va hasta la caja de electrónica.
- Conectividad: los motores NEMA17 y encoders disponen de conectores rápidos en sus extremos; en la caja electrónica todos los cables están conectados mediante conectores (no todo es fijo), mientras que en los tramos de brazo se utiliza termocontraíble para proteger uniones.
- Estrategia práctica: cada rama contempla una holgura razonable y un radio mínimo en las curvas para evitar fatiga; el cableado se ancla en puntos fijos en cada segmento con alivio de esfuerzos.

### 4.19 Disipación térmica de la electrónica

La caja electrónica del SCARA aloja la placa controladora (Arduino Mega + RAMPS), multiplexor y drivers. La solución térmica adoptada consta de un ventilador tipo cooler de PC alimentado a 12 V que extrae el aire caliente de la caja de electrónica de forma continua. La fuente de 12 V está dentro de la misma carcasa del SCARA.

- Observación práctica: la extracción forzada mediante el ventilador mantiene los drivers en régimen térmico aceptable durante ensayos; se recomienda vigilar temperaturas superficiales de los disipadores de los DRV8825 — si superan ~70 °C en operación continua, aumentar flujo de aire o mejorar disipación.
- Disposición: la electrónica se separó físicamente de las piezas impresas para evitar exposición directa al calor; se sugiere mantener camino de flujo entre la entrada (aire fresco) y salida (ventilador) con rejillas y filtros si se opera en ambientes sucios.

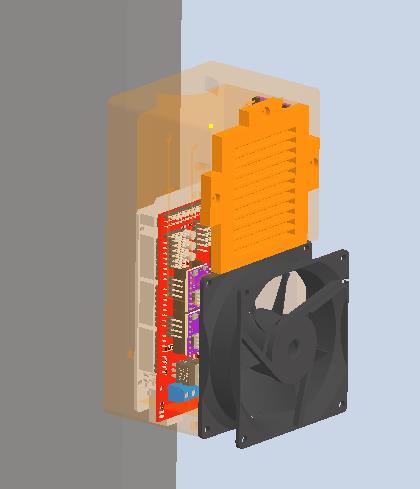
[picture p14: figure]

Figura 4.14 – Caja para electrónica con cooler disipador

### 4.20 Vinculación CAD / Anexos

Los modelos CAD, exports de STL y planos asociados a cada una de las piezas y ensamblajes descritos se han incluido en los anexos:
- Anexo 4.A — Lista de Ensamblaje y diseño.xlsx (https://github.com/bellomifede-dot/Proyecto-Final---Lavadora-de-Ecus/blob/main/Lista%20de%20Ensamblaje%20y%20dise%C3%B1o.xlsx)
- Anexo 4.B — Piezas Robot SCARA (https://github.com/bellomifede-dot/Proyecto-Final---Lavadora-de-Ecus/tree/main/Piezas/Robot%20SCARA)
- Anexo 4.C — Ensamblaje SCARA.iam (https://github.com/bellomifede-dot/Proyecto-Final---Lavadora-de-Ecus/blob/main/Piezas/Robot%20SCARA/Ensamblajes/Ensamblaje%20SCARA.iam) (.ipt)

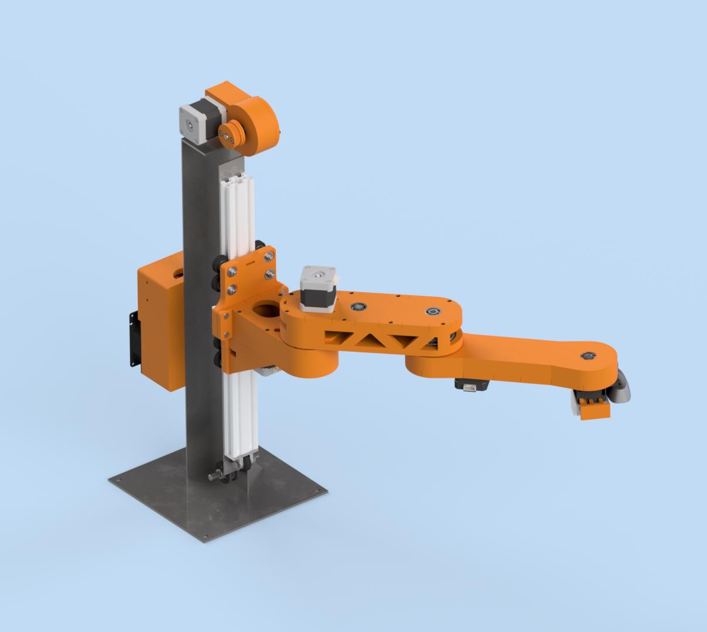
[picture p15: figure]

Figura 4.15 – Ensamblaje robot SCARA

### 5 Diseño Electrónico del Robot SCARA

### 5.1 Arquitectura electrónica

Resumen de bloques y flujo de energía / señales
- PC (GUI Python) ←→ Serial USB → Arduino Mega 2560
- Gestiona interfaz de usuario, scripting, recepción de POS ... y envío de comandos (moveJ, home, enable, gripper, s).
- Arduino Mega 2560 → RAMPS (shield) → drivers de motor (DRV8825) → Motores (NEMA17):
- RAMPS 1.4 actúa como placa intermedia para señales STEP/DIR/EN y alimentación 12 V.
- DRV8825 controla los coils de cada motor vía chopping; potenciómetro Vref para I_limit.
- Motores:
- NEMA17 (3 × alto torque; 1 × pancake).
- Periféricos y sensores:
- Encoders magnéticos AS5600 (I²C), TCA9548A (multiplexor I²C), servo gripper SG90 (control PWM), endstops (INPUT_PULLUP).
- Alimentación:
- PSU principal: 12 V, 15 A.
- Pc 5 V para lógica/servos.

Asignación de pines
- J1 (X): STEP=54, DIR=55, EN=38, endstop X_MIN=3
- J2 (Y): STEP=60, DIR=61, EN=56, endstop Y_MIN=14
- Z: STEP=46, DIR=48, EN=62, endstop Z_MIN=18
- J6 (E0): STEP=26, DIR=28, EN=24, endstop E0_MIN=19
- Gripper servo: pin 11

### 5.2 Cálculo de consumo de corriente

Datos de diseño
- 3 × NEMA17 alto torque → 1.7 A por fase → 3 × 1.7 A = 5.1 A
- 1 × NEMA17 pancake → 1.0 A por fase = 1.0 A
- Total motores:

### Imotores = 5.1 + 1.0 = 6.1 A

- Margen de seguridad 30%:

### Imargen = 6.1 × 1.3 = 7.93 A

- PSU nominal considerada: 12 V

Potencia requerida

### P = V ⋅ I = 12 V × 7.93 A ≈ 95.2 W

Fuente seleccionada
- Fuente propuesta en proyecto: 12 V, 15 A → Pfuente = 12 ⋅ 15 = 180 W.
- Razonamiento: cubre el consumo calculado (≈95 W) y deja margen amplio para picos, ventilación, bombas u otros periféricos futuros.

Consumo circuito de comando
- Arduino Mega: 100 mA (asumido)
- 4 × AS5600: 4 × 8 mA = 32 mA
- TCA9548A: 2 mA
- 4 × DRV8825 (consumo lógico): 4 × 10 mA = 40 mA
Total: 100 + 32 + 2 + 40 = 174 mA → con margen práctico → 250 mA.

### 5.3 Selección y dimensionamiento de fuente de alimentación

Requisitos
- Riel 12 V para los drivers/motores: corriente continua estimada con margen ≈ 7.93 A.
- Recomendación: 12 V, 15 A (180 W). Ventajas:
- Suficiente margen para picos y expansión.
- Permite alimentar ventilador caja, drivers, y opcionalmente algún periférico DC.

### 5.4 Análisis de consumo en pines críticos del microcontrolador

Límites del microcontrolador (ATmega2560)
- Corriente máxima por pin: 40 mA (límite ABSOLUTO)
- Recomendado (por seguridad y fiabilidad): ≤ 20 mA por pin
- Máx por puerto (grupo de 8 pins): ≈ 100 mA
- Máx consumo total VCC: ≈ 200 mA

Evaluación del diseño actual
- Pines STEP/DIR: señales digitales de bajo consumo (µA–mA) → sin riesgo.
- I²C (AS5600 y TCA9548A): consumo de bus µA–mA → sin riesgo.

Conclusión: con la arquitectura actual no hay riesgo de exceder límites de pines del ATmega2560.

### 5.5 Drivers de motores y disipación térmica

1) Estimación de corriente límite (I_limit) a partir de Vref
La relación típica (válida para muchas placas Pololu/compatibles) es aproximadamente:

Ilimit ≈

Vref

8 ⋅ Rsense

donde Rsensees la resistencia de medida (valor en la placa del drv).
Importante: diferentes placas usan distintas resistencias sense (típicamente 0.05 Ω o 0.1 Ω). Si no conocés Rsense, conviene comprobar la placa o medir la resistencia entre los pads SENSE.
Calculemos dos casos típicos:
- Si Rsense = 0.1 Ω:

Ilimit =

0.85
8 × 0.1

=

0.85
0.8

= 1.0625 A

→ Insuficiente para motores con 1.7 A.
- Si Rsense = 0.05 Ω:

Ilimit =

0.85
8 × 0.05 =

0.85
0.4

= 2.125 A

→ Adecuado para motores configurados a 1.7 A.
Interpretación: dado que trabajás con motores de 1.7 A/fase, la segunda hipótesis (R_sense ≈ 0.05 Ω) es la coherente si Vref=0.85 V. Verifica físicamente Rsenseimpreso en la placa o consulta la documentación del módulo. Si fuese 0.1 Ω, Vref debería aumentarse para alcanzar 1.7 A (con las precauciones abajo).

2) Comportamiento térmico y disipación
Contexto: la disipación en el DRV8825 depende de: tensión de alimentación (12 V), corriente por fase (I_set), microstepping, Rds(on) de MOSFETs internos y duty cycle. El cálculo exacto requiere Rds_on y modelo transistor; aquí se da un método práctico + estimaciones conservadoras.

Regla práctica:
- Para I_limit > 1 A por fase conviene disipador + ventilador.
- Para I_limit ≈ 1.7 A por fase, esperar que los módulos alcancen temperaturas elevadas sin ventilación — la ventilación en la caja es adecuada.

### 5.6 Esquemas Electrónicos Scara/Anexos

- Anexo 5.A —Esquema Scara.png (https://github.com/bellomifede-dot/Proyecto-Final---Lavadora-de-Ecus/blob/main/Esquemas%20Electronicos/Esquema%20Scara.png)

### 6 Control y Software del Robot SCARA

### 6.1 Estrategia de control

El control del SCARA está implementado en dos capas:
- Capa baja (firmware Arduino / drivers): control open-loop de motores paso a paso mediante AccelStepper (drivers en modo DRIVER). El firmware (Control SCARA.ino) se encarga del homing, ejecución de trayectorias simples y gestión de enable/disable de drivers, límites por software, stop de emergencia y control del gripper (servo).
- Pines, límites y home definidos por macros (ej.: X_STEP_PIN=54, J1_HOME_POS, J1_MIN/J1_MAX, etc.).
- Movimientos no bloqueantes: moveL (objetivos absolutos) y moveJ (deltas por eje) — moveJ construye movimientos relativos por eje y el firmware los ejecuta con AccelStepper::move() y run(). Al finalizar un movimiento se publica por serial la línea "POS J1 ... J2 ... Z ... J6 ...".
- Homing interrumpible con lectura de endstops y setCurrentPosition() al concluir el homing.
- Capa alta (PC / GUI Python): Actúa como controlador maestro y planificador: genera comandos de alto nivel (GOTO en coordenadas cartesianas), usa la librería de cinemática inversa para calcular ángulos, pasa esos ángulos a unidades/ pasos (con MotionModel / robot_config.json) y envía comandos moveJ/moveL por serial. También gestiona scripts, jog, joystick PS4 y la lógica de integración con visión (p. ej. obtener_ecu_y_guardar() que solicita coordenadas del sistema de visión). Ejemplos de uso: envío de moveJ J1 1000 800 400 (delta, vmax, amax). Ver implementación y parsing en la GUI.

Ventajas de la estrategia actual
- Arquitectura sencilla y robusta para prototipado (firmware simple + procesador potente en PC).
- Separación clara entre la cinemática/planificación (PC) y la ejecución de bajos niveles (firmware).
- Permite operación manual, scripting y teleoperación por joystick.

Limitaciones / riesgos
- Control open-loop (steppers sin encoders): sin retroalimentación, ocurren perdidas de pasos por sobrecarga o colisiones; el firmware no corrige posición en tiempo real.
- Protocolos de comunicación simples (sin ACKs): posible pérdida o desincronización si hay ruido serial.
- Parámetros "duros" en firmware (límites y constantes) que requieren mantenimiento manual si se cambian mecánicos o configuración de microstepping.

### 6.2 Implementación de cinemática inversa

Librería usada
La cinemática está implementada en scara_kinematics.py (módulo propio): ofrece forward_kinematics(...) e inverse_kinematics(...). En ese archivo se definen longitudes mecánicas y offsets (ej.: L1 = 160, L2 = 200, OFFSET_X = 135) y utilidades para convertir grados↔radianes.
scara_kinematics
Flujo de cálculo
1. Usuario/ rutina indica objetivo cartesiano (X, Y, Z, φ_abs).
2. La GUI llama inverse_kinematics(x, y, z, phi_abs) y obtiene una (o varias) soluciones para (θ1, θ2, d, φ_m).

scara_kinematics
3. Se convierte cada ángulo/posición en pasos mediante MotionModel.units_to_steps(eje, valor) (usa robot_config.json con pasos/mm o pasos/deg).
4. Se envía moveJ al firmware; el firmware ejecuta el movimiento y, al terminar, publica la posición actual (POS ...) que la GUI usa para actualizar la interfaz.

Consideraciones numéricas
- inverse_kinematics devuelve 0 o 2 soluciones (codo arriba/abajo). La GUI elige la primera solución válida o puede elegir según criterio (mínimo movimiento, evitar singularidades).

- Es crítico que los parámetros geométricos (L1, L2, OFFSET_X) sean correctos y estén sincronizados entre la documentación, la librería y cualquier archivo de configuración (para evitar errores de IK).

### 6.3 Secuencia de homing

Descripción de la secuencia implementada (firmware)
- El comando serial home inicia homing eje a eje: se llama homeAxis(...) para J1, J2,
Z. J6 no se mueve (simplemente setCurrentPosition(J6_HOME_POS)).
- homeAxis funciona así:
- Puede aplicar una inversión temporal de los pines de dirección para asegurar el sentido correcto (tempInvert para J2 está activado en el código actual).
- Ajusta velocidad con setMaxSpeed / setSpeed y avanza hasta que el endstop cambia de estado (en el código: while (digitalRead(endstopPin) == HIGH) — por lo tanto los endstops están configurados como INPUT_PULLUP y normalmente HIGH).
- Al detectarse el endstop hace delay(200) y motor.setCurrentPosition(homingPosition) para fijar la posición home definida por macro (J1_HOME_POS, etc.).
- El homing es interrumpible por el comando s (stop).

### 6.4 Comunicación con la PC

Protocolo actual y elementos clave
- Baudrate: el firmware inicializa Serial.begin(115200); y la GUI abre puerto serial con BAUDRATE definido, timeout y listener. La GUI no bloquea esperando confirmación de los comandos; en cambio, hay un listener que muestra las líneas recibidas del Arduino en el log (la GUI interpreta líneas como "POS J1 ..." para actualizar estado).

GUI
- Comandos soportados (por firmware):
- home — homing completo.
- moveJ J1 <steps> <vmax> <amax> ... — movimiento relativo por ejes (pares por eje).
- moveL J1 <target> J2 <target> ... — objetivos absolutos (no bloqueante).
- enable on/off — energizar / desenergizar drivers.
- gripper open / gripper close — control servo.
- s o línea vacía — STOP global.
- Al terminar movimientos, firmware envía Movimiento finalizado y POS J1 ... con posiciones en pasos.

### 6.5 Integración con el sistema de visión

Arquitectura de integración
- El sistema de visión (VisionArtificial.py) detecta marcadores ArUco, filtra la pose y ejecuta YOLO on-demand / periódico para clasificar tipo de ECU y asociar bounding box → marcador; además expone un servidor TCP que responde a GET devolviendo {"type":..., "X":..., "Y":..., "Z":..., "Yaw":...} con la posición en marco world (ya aplicada la corrección por offsets del tipo de ECU).

VisionArtificial
- La GUI ejecuta obtener_ecu_y_guardar() que invoca el módulo de visión y luego realiza:
1. Conversión de la pose cartesiana de visión → IK (scara_kinematics.inverse_kinematics).
2. Conversión de ángulos a pasos (MotionModel).
3. Envío de comando moveJ al firmware para ejecutar pick/place.

GUI
Puntos críticos y comprobaciones
- Hand-eye / calibración: la precisión de la conversión pixel→world→robot depende completamente de:
- calibración intrínseca de la cámara (archivo calibracion_camara.npz que el vision code carga),
- definición correcta de known_markers_world (matrices T_w_m en mm),
- y la coherencia de unidades entre visión y cinemática (mm/°).
Si estos no están ajustados, la IK recibirá coordenadas erróneas y la manipulación fallará.
- Asociación bbox ↔ marker: el código usa distancia centro bbox ↔ centroid marker con umbral MATCH_MAX_DIST_PIX. Debes verificar este umbral en distintas condiciones de iluminación/zoom.
- Tiempo y sincronización: la GUI llama al servidor de visión y espera resultado; visión puede ejecutar YOLO on-demand y toma varios frames — la latencia debe medirse y tolerancias definidas.

### 6.6 Códigos Scara/Anexos

- Anexo 6.A — Código/SCARA/Complementos motion_model.py (https://github.com/bellomifede-dot/Proyecto-Final---Lavadora-de-Ecus/blob/main/C%C3%B3digo/SCARA/Complementos/motion_model.py)
- Anexo 6.B— Código/SCARA/Complementos scara_kinematics.py (https://github.com/bellomifede-dot/Proyecto-Final---Lavadora-de-Ecus/blob/main/C%C3%B3digo/SCARA/Complementos/scara_kinematics.py)
- Anexo 6.C— Código/SCARA Control SCARA.ino (https://github.com/bellomifede-dot/Proyecto-Final---Lavadora-de-Ecus/blob/main/C%C3%B3digo/SCARA/Control%20SCARA.ino)
- Anexo 6.D— Código/SCARA GUI_Scara.py (https://github.com/bellomifede-dot/Proyecto-Final---Lavadora-de-Ecus/blob/main/C%C3%B3digo/SCARA/GUI_Scara.py)

### BLOQUE II – LAVADORA DE ECUs

### 7. DISEÑO MECÁNICO DE LA LAVADORA DE ECUs

### 7.1 Requerimientos funcionales

La lavadora de ECUs fue concebida como un módulo automatizado destinado a la limpieza controlada de placas electrónicas automotrices. El sistema debe aceptar placas con dimensiones máximas de:

- Largo: 125 mm
- Ancho: 105 mm
- Espesor de PCB: 1,6 mm
- Peso máximo considerado: 150 g
El sistema opera con una sola ECU por ciclo, con un tiempo objetivo total de aproximadamente 30 minutos, incluyendo etapa de aspersión y limpieza ultrasónica. El movimiento principal es realizado por un sistema XY que desplaza la ECU dentro de la cámara de lavado, permitiendo además la rotación de la pieza para garantizar la limpieza automática de ambas caras sin intervención manual.
El nivel de automatización es total: una vez iniciado el ciclo, el proceso se ejecuta sin asistencia del operador.
El fluido de limpieza utilizado es alcohol isopropílico al 99%, lo que impone restricciones adicionales en términos de compatibilidad química y seguridad.
El diseño contempla integración física y funcional con el robot SCARA, aunque puede operar como módulo independiente.
Desde el punto de vista de diseño proyectado, se plantea un grado de protección IP68; sin embargo, el prototipo actual no incorpora juntas industriales ni sellos certificados, por lo que este valor debe considerarse como objetivo de diseño futuro.

### 7.2 Diseño del sistema de movimiento XY

El sistema de posicionamiento está compuesto por:

- Guías lineales con varillas lisas.
- Carro desplazable impreso en 3D.
- Transmisión mediante tornillo helicoidal tipo CNC.
- Accionamiento directo mediante motores paso a paso NEMA17.
El tornillo helicoidal convierte el movimiento rotacional del motor en desplazamiento lineal del carro, garantizando precisión y control posicional.
La masa total desplazada por el sistema (estructura móvil + ECU + motores + mecanismo de rotación) es aproximadamente:
m = 1,2 kg
La precisión objetivo del sistema es del orden de ±1 mm, coherente con la resolución del motor paso a paso y el paso del tornillo helicoidal.
El movimiento vertical (Z) permite una elevación de 50 mm hacia arriba y 50 mm hacia abajo, controlado mediante finales de carrera mecánicos.

### 7.3 Sistema de sujeción de la ECU

La ECU se sujeta por los bordes mediante un sistema de grippers actuados. La presión se aplica lateralmente evitando esfuerzos sobre componentes electrónicos.

Características:
- Sujeción por bordes.
- Sistema de volteo automático.
- Recubrimiento de contacto con goma.
- Capacidad para soportar vibraciones del sistema ultrasónico.
- Accionamiento mediante servomotores MG946.
El diseño busca aplicar la mínima fuerza necesaria para garantizar fijación sin comprometer la integridad estructural del PCB.

### 7.4 Sistema de aspersión

El sistema de aspersión está compuesto por:

- Dos inyectores de nafta automotrices adaptados.
- Presión de trabajo: 3 bar.
- Distancia boquilla–placa: entre 20 mm y 40 mm.
- Tiempo mínimo de exposición: 5 minutos.
- Tanque abierto de 5 litros.
- Tuberías de poliamida.
- Bomba eléctrica automotriz de 12 V.
La presión de 3 bar permite generar un chorro atomizado suficiente para remover contaminantes adheridos sin dañar componentes electrónicos.
El funcionamiento es intermitente, ya que no se dispone de regulador de presión.

### 7.5 Sistema de limpieza ultrasónica

El diseño proyectado contempla un sistema ultrasónico con:

- Frecuencia nominal: 40 kHz.
- Volumen de batea: 2 litros.
- Material: chapa común.
- Tiempo de inmersión teórico: 15 minutos.
- Inmersión total de la ECU.
No se dispone actualmente de control de temperatura ni sistema de secado posterior. Desde el punto de vista técnico, 40 kHz constituye una frecuencia adecuada para limpieza fina en placas electrónicas, ya que genera cavitación controlada sin agresividad excesiva.
Para el dimensionamiento conceptual se adopta una potencia estimada de 100 W, coherente con el volumen de trabajo.

### 7.6 Diseño estructural y hermetización

La estructura principal está fabricada en:

- Chapa galvanizada de 2 mm.
- Paneles de acrílico transparente para inspección visual.
- Tapa superior.
- Sellado mediante adhesivo tipo parabrisas.
La estructura es soldada con estaño.

No posee:
- Juntas industriales.
- Bandeja de contención.
- Aislamiento acústico.
Las dimensiones totales quedan pendientes de definición.

### 7.7 Consideraciones de seguridad

El prototipo actual no incorpora:

- Ventilación forzada.
- Sensores de tapa.
- Sensor de nivel.
- Sensor de temperatura.
- Protección anti-chispa.
- Normativa ATEX.

Dado que se emplea alcohol isopropílico al 99%, inflamable, la implementación futura deberá incluir sistemas de ventilación, separación de compartimentos húmedo/seco y protecciones eléctricas certificadas.

### 8. CÁLCULOS MECÁNICOS

### 8.1 Cálculo de fuerzas en el sistema XY

Masa desplazada:
m = 1,2 kg
Si consideramos una aceleración moderada de: a = 0,5 m/s²
La fuerza necesaria es:
F = m · a
F = 1,2 × 0,5
F = 0,6 N
Incluso considerando fricción y pérdidas, suponiendo un coeficiente de fricción equivalente a 0,2:
F total ≈ 1 N
Este valor es extremadamente bajo comparado con la capacidad de un NEMA17 (≈ 0,4 N·m de torque).
Si el tornillo helicoidal tiene un radio efectivo de 5 mm:
r = 0,005 m
El torque requerido es:
T = F × r
T = 1 × 0,005
T = 0,005 N·m

Comparado con:
T motor ≈ 0,4 N·m
Existe un margen de seguridad superior a 80 veces.
Conclusión: el sistema está sobredimensionado desde el punto de vista de torque.

### 8.2 Cálculo de presión de aspersión

Presión nominal:
P = 3 bar = 300.000 Pa
La velocidad teórica de salida (Bernoulli): v = √(2P/ρ)
Densidad alcohol isopropílico ≈ 785 kg/m³
v = √(2 × 300.000 / 785)
v ≈ 27,6 m/s
Esta velocidad garantiza energía cinética suficiente para desprender contaminantes superficiales.

### 8.3 Selección de bomba

Bomba automotriz:
- Tensión: 12 V
- Corriente estimada: 10 A
- Funcionamiento intermitente
- Presión nominal: 3 bar
Potencia eléctrica:
P = V × I
P = 12 × 10
P = 120 W

### 8.4 Cálculo de potencia mecánica del sistema XY

Trabajo para elevar 1,2 kg 50 mm:
W = m·g·h
W = 1,2 × 9,81 × 0,05
W ≈ 0,59 J

Incluso repitiendo el ciclo varias veces, la potencia requerida es insignificante frente a la bomba. Conclusión: la bomba es el principal consumidor energético del sistema.

### 8.5 Análisis de vibraciones

El sistema ultrasónico (40 kHz) opera a frecuencias muy superiores a la frecuencia natural estructural estimada (<100 Hz), por lo que no existe riesgo de resonancia estructural con el sistema XY.

El desacople actual se limita al adhesivo de montaje, lo cual no constituye un aislamiento vibratorio formal.

### 9. DISEÑO ELECTRÓNICO DE LA LAVADORA

### 9.1 Arquitectura electrónica

La lavadora de ECUs posee una arquitectura electrónica independiente del robot SCARA, basada en:
- Microcontrolador: Arduino Mega 2560
- Shield de potencia: RAMPS 1.4
- Drivers para motores paso a paso
- Fuente principal de 12 V
- Fuente secundaria de 5 V para servomotores
- Etapas de conmutación para bomba e inyectores El sistema se divide en tres bloques principales: 1 Bloque de control
- Arduino Mega
- Comunicación con PC vía USB
- Lógica programada de seguridad
- Gestión de secuencia automática 2 Bloque de potencia 12 V
- Bomba automotriz (3 bar)
- Dos inyectores de nafta
- Dos motores paso a paso NEMA17
- Electrónica auxiliar de 12 V
3 Bloque de potencia 5 V
- Cuatro servomotores MG946
- Lógica de control de actuadores

La comunicación con la PC permite iniciar ciclos, supervisar estado y enviar comandos.

### 9.2 Cálculo de consumo total del sistema

Se consideran los siguientes consumos estimados:
Motores paso a paso
2 × NEMA17
Corriente nominal: 1,7 A por motor Total stepper = 2 × 1,7
Total stepper = 3,4 A

Bomba automotriz
Corriente estimada:
bomba = 10 A

Inyectores de nafta
Corriente típica ≈ 1 A cada uno inyectores = 2 × 1
inyectores = 2 A

Servomotores MG946
Consumo pico ≈ 2,5 A cada uno
Sin embargo, definiste que nunca funcionan más de 2 simultáneamente: Servos max = 2 × 2,5
servos max = 5 A

Consumo electrónica (Arduino + lógica) Aproximadamente:
control ≈ 0,3 A

Corriente total en línea de 12 V
Motores + bomba + inyectores: Corriente 12V = 3,4 + 10 + 2
Corriente 12V = 15,4 A
Aplicando margen de seguridad del 30%:
Corriente 12V_diseño = 15,4 × 1,3
Corriente 12V_diseño ≈ 20 A
Cabe destacar que no funciona todo al mismo tiempo, este es un hipotético caso.

Corriente total en línea de 5 V Servos + lógica:
Corriente 5V = 5 + 0,3
Corriente 5V = 5,3A
Aplicando margen del 30%:
Corriente 5V diseño ≈ 7 A

### 9.3 Dimensionamiento de fuentes de alimentación

Fuente 12 V
Corriente mínima requerida:
20 A
Potencia:
P = V × I
P = 12 × 20
P = 240 W
Se recomienda una fuente de:
12 V – 25 A (300 W)
Esto permite margen térmico y evita operación al límite.

Fuente 5 V para servos
Corriente requerida:
7 A
Potencia:
P = 5 × 7
P = 35 W
Se recomienda una fuente externa de:
5 V – 10 A
No se recomienda alimentar los servos desde el regulador del Arduino debido a las corrientes elevadas y picos transitorios

### 9.4 Sistema de protección contra sobrecorriente

Actualmente el sistema incorpora:
- Fusible dedicado para la bomba de nafta.
Desde el punto de vista de ingeniería, deberían incorporarse:
1. Fusible general en la entrada de 12 V.
2. Fusible independiente para motores.
3. Protección contra inversión de polaridad.
4. Diodos flyback en cargas inductivas.
5. Relé o MOSFET de potencia con disipación térmica adecuada.
La ausencia de estas protecciones constituye una limitación del prototipo y se propone como mejora futura.

### 9.5 Sensores de fin de carrera y lógica de seguridad

El sistema dispone de:
- 2 finales de carrera mecánicos
- Uno para límite superior.
- Uno para límite inferior.
- Lógica de seguridad implementada por software.
Funcionamiento:
Si el sistema detecta activación de final de carrera, detiene el movimiento del eje correspondiente.
No se dispone de:
- Sensor de tapa.
- Sensor de nivel.
- Sensor de temperatura.
- Detección de sobrecorriente programada.

Desde el punto de vista de seguridad industrial, estos sensores deberían incorporarse en una versión industrializada del sistema.

### 9.6 Esquema eléctrico general (descripción conceptual)

El esquema eléctrico general se estructura de la siguiente manera:

Entrada 220 V AC
→ Fuente switching 12 V
→ Distribución a:
- Drivers NEMA17
- Bomba
- Inyectores
- Regulador / fuente 5 V externa Fuente 5 V
→ Servomotores
→ Lógica auxiliar
Arduino Mega
→ Señales de control a:
- Drivers paso a paso
- Servos
- Relé/MOSFET bomba
- Inyectores

- Lectura finales de carrera
Se recomienda mantener separación física entre:
- Zona de potencia
- Zona de control
- Zona húmeda
En el prototipo actual esta separación no es formal, lo que constituye otra mejora futura.

Conclusión Técnica del Bloque II
Desde el punto de vista de ingeniería:
- El sistema mecánico está sobredimensionado en torque.
- La bomba representa el mayor consumo energético.
- El sistema eléctrico requiere mejoras en protección.
- La arquitectura es funcional para prototipo académico.
- Existen oportunidades claras de mejora en seguridad industrial.

### 9.7 Lavadora de ECUs / Anexos

Los Esquemas electrónicos y códigos de la lavadora de ECUs se han incluido en los anexos:

- Anexo 9.A — Esquema Lavadora.png (https://github.com/bellomifede-dot/Proyecto-Final---Lavadora-de-Ecus/blob/main/Esquemas%20Electronicos/Esquema%20Lavadora.png)
- Anexo 9.B — Comunicacion.ino (https://github.com/bellomifede-dot/Proyecto-Final---Lavadora-de-Ecus/blob/main/C%C3%B3digo/Lavadora%20ECU/Comunicacion.ino)
- Anexo 9.C — Lavadora_ECU.ino (https://github.com/bellomifede-dot/Proyecto-Final---Lavadora-de-Ecus/blob/main/C%C3%B3digo/Lavadora%20ECU/Lavadora_ECU.ino)

### BLOQUE III – SISTEMA DE VISIÓN E INTELIGENCIA ARTIFICIAL

### 10. Sistema de Visión Artificial

### 10.1 Selección de cámara

La cámara que se utilizó para este proyecto es una Logitech C270 de resolución 720p, la se optó por una cámara de 720p por el presupuesto que involucraba comprar una cámara de más alta calidad (las cámaras de 1080p estaban más del triple), se eligió el modelo Logitech C270 por sus buenas reseñas y relación precio calidad.

### 10.2 Flujo de procesamiento de imagen

El sistema procesa cada fotograma mediante un pipeline determinista orientado a estimación de pose y clasificación tipo ECU. El flujo implementado en el prototipo es:

1. Adquisición — captura directo con OpenCV (VideoCapture(0)).
2. Preprocesado — conversión a gris para la detección de marcadores ArUco.
3. Detección ArUco — ArucoDetector.detectMarkers obtiene esquinas y IDs.
4. Construcción correspondencias WORLD↔IMG — para cada marcador fijo conocido (tabla known_markers_world) se construyen puntos 3D en WORLD y sus proyecciones en píxeles.

5. Estimación pose cámara en WORLD — solvePnP con los marcadores fijos → rvec_cam, tvec_cam, T_cam_world y su inversa T_world_cam. Esto define el transformador que permite pasar entre frames.
6. Candidatos objetivo (target_id) — se extraen centroides de los marcadores detectados con id == target_id.
7. Detección YOLO (OBB/boxes) — inferencia en RGB con el modelo entrenado (best.pt) en dos modos: on_demand (trigger por p o GET TCP) o periodic (cada YOLO_PERIOD frames). Se selecciona la detección de mayor confianza y se guarda en historial para voting.
8. Asociación bbox↔marker y locking — si existe bbox y candidatos marker se asocian por mínima distancia en píxeles (umbral MATCH_MAX_DIST_PIX); se mantiene un lock temporal con tolerancia LOCKED_MAX_MISSES.
9. Estimación pose del objeto — solvePnP sobre los corners del marker lockeado → T_cam_obj; si T_world_cam es válido: T_world_obj = T_world_cam @ T_cam_obj.
10. Suavizado — filtrado anisotrópico en X/Y/Z (alpha_xyz) y SLERP para rotación (alpha_rot), con fase de convergencia rápida tras adquisición de lock (parámetros FAST_*).
11. Salida/visualización — ejes proyectados, bbox (si aplica), y etiqueta de tipo en esquina superior derecha con color por clase.
12. Interfaz — servidor TCP (GET/EXIT) que puede disparar una corrida YOLO on-demand y devuelve JSON {type, X, Y, Z, Yaw} con OFFSET aplicado por tipo.

### 10.3 Modelo de inteligencia artificial utilizado

Arquitectura y pesos
- Backbone / arquitectura: YOLOv8m-obb (modelo base yolov8m-obb.pt usado como pre-entrenado y adaptado por transfer learning). El resumen del modelo en el log indica 320 capas y ≈ 26.4 M parámetros; la cabeza final es de tipo OBB para cajas orientadas.
- Framework: Ultralytics.
- Formato de salida: soporta boxes (xyxy) y obb (oriented bounding boxes). El código toma tanto r.boxes como r.obb y elige la detección de mayor confianza.

Modo de uso
- Inferencia vía model.predict.
- Filtrado: MIN_CONF_ACCEPT = 0.30 en el pipeline.

- El sistema guarda la mejor detección por frame y mantiene un historial de etiquetas (LABEL_HISTORY_LEN = 7) para voting (acepta etiqueta si >= LABEL_VOTE_MIN).

Rendimiento medido
- Precisión (BBOX): 0.994
- Recall (BBOX): 0.994
- mAP50: 0.992
- mAP50-95: 0.990
- Velocidad promedio por imagen: 0.538 ms preprocess + 10.401 ms inference + 3.867 ms postprocess = 14.805 ms / imagen → ≈ 67.5 FPS.

### 10.4 Entrenamiento y validación

Plataforma / entorno
- Entrenamiento realizado en Google Colab (Tesla T4 GPU, ~15 GB memoria GPU). Ultralytics v8.3.30 y PyTorch con CUDA:0.

Dataset
- Estructura: entrenamiento en /content/drive/MyDrive/Entrenamiento9/train y validación en /content/drive/MyDrive/Entrenamiento9/valid.
- Número de imágenes: train: 2703 imágenes, valid: 256 imágenes.
- Distribución por clase: Ecu-1 = 43 instancias, Ecu-2 = 181 instancias (total 224).

Hiperparámetros y configuración
- epochs=120, imgsz=640, batch=16, device='cuda', workers=2.
- Optimizer: auto → Ultralytics seleccionó AdamW con lr≈0.001667 y momentum 0.9.
- Augmentations destacadas: Blur, MedianBlur, ToGray, CLAHE; mosaic=1.0; translate=0.1, scale=0.5, fliplr=0.5, entre otros parámetros estándar de la configuración.
- Loss head: box/cls/dfl/pose/… configurados por defecto del head OBB (DFL activo).

Curvas y convergencia
- El entrenamiento muestra reducción sostenida de box_loss, cls_loss y dfl_loss durante las 120 epochs.
- El log final muestra box_loss ≈ 0.1546, cls_loss ≈ 0.1346, dfl_loss ≈ 1.373 en epoch final.
- Tiempo total entrenamiento: 120 epochs en 2.112 horas → 2 h 6 min 43.2 s.

Resultados de validación final
- All: precision 0.994 — recall 0.994 — mAP50 = 0.992 — mAP50-95 = 0.990.
- Por clase:
- Ecu-1 (43 inst.): P=0.999, R=1.000, mAP50=0.995, mAP50-95=0.992
- Ecu-2 (181 inst.): P=0.989, R=0.989, mAP50=0.989, mAP50-95=0.987

Inference speed (métricas de tiempo)
- Preprocess 0.538 ms | Inference 10.401 ms | Postprocess 3.867 ms → ≈14.805 ms /
imagen (≈67.5 FPS). Esto es medido en el entorno Colab con batch per image y configura un buen margen para uso en tiempo real en CPU/GPU según despliegue.

Archivos generados
- Pesos: last.pt y best.pt (≈53.2 MB).
- Carpetas con logs, labels.jpg (plot labels), TensorBoard logs y curvas de metrics en project/ecu_yolo_obb.

### 10.5 Conversión de coordenadas píxel a coordenadas reales

- La calibración intrínseca se carga desde calibracion_camara.npz produciendo Ky dist.
- Para estimar la pose de la cámara en el sistema WORLD se construyen correspondencias 3D (puntos world de marcadores fijos) ↔ 2D (corners detectados), y se aplica cv2.solvePnP → rvec_cam, tvec_cam. Esto define Tcam←world. Su inversa Tworld←camse calcula por inversión de la rotación y traslación.
- Para la pose del objeto (marcador objetivo) se utiliza solvePnP con marker_corners_local (4 puntos en 3D definidas por markerLength = 37.0 mm) y los corners detectados en imagen; esto da Tcam←obj. Entonces:

Tworld←obj = Tworld←cam Tcam←obj

y la posición en WORLD es la translación de Tworld←obj.
- El pipeline aplica offsets por tipo rotados sólo en Z por el yaw estimado:

### pecu = pobj + Rz(yaw) OFFSET

Filtrado y robustez
- Se aplica filtrado anisotrópico en X,Y,Z con alpha_xyz y SLERP para rotaciones con alpha_rot. Al adquirir un lock se dispone una fase de convergencia rápida (FAST_ALPHA_*) o una inicialización instantánea
(INSTANT_INIT_ON_LOCK).

### 10.6 Comunicación entre PC y microcontrolador

Protocolo implementado
- Servidor TCP en 0.0.0.0:5000 (socket TCP, single-client loop, SO_REUSEADDR).
- Comandos:
- GET — dispara corrida YOLO on-demand (si el modelo está cargado), espera hasta YOLO_WAIT_TIMEOUT segundos por los frames solicitados y devuelve JSON con {"type":..., "X":..., "Y":..., "Z":..., "Yaw":...} o {"error":"no detection"}.
- EXIT — responde {"status":"bye"} y cierra la sesión.
- Otros comandos → {"error":"unknown command"}.
- Formato: ASCII/UTF-8 JSON simple, fácil de parsear en MCU/PLC.
- Comportamiento y robustez: el servidor utiliza synchronización (yolo_done_event) para coordinar la ejecución on-demand; se utiliza force_yolo_frames para asegurar que el bucle principal ejecute YOLO los siguientes N frames. Se usan timeouts y accept() con timeout para un apagado limpio.

### 10.7 Códigos Vision/Anexos

- Anexo 10.A — Código/Vision Artificial VisionArtificial.py (https://github.com/bellomifede-dot/Proyecto-Final---Lavadora-de-Ecus/blob/main/C%C3%B3digo/Vision%20Artificial/VisionArtificial.py)

### BLOQUE IV – INTEGRACIÓN DEL SISTEMA

### 11. Integración del sistema

Esta sección describe cómo se conectan y coordinan entre sí los subsistemas del proyecto: visión (PC + cámara), manipulador SCARA, y la “caja” lavadora. El texto es descriptivo y refleja la implementación actual del prototipo (arquitectura, protocolos, topología física, flujo operativo, manejo de errores y limitaciones conocidas).

### 11.1 Arquitectura general

La arquitectura es en topología estrella con la PC como nodo central. Los subsistemas y su relación son:

- PC (nodo maestro): ejecuta el software de visión y la interfaz de usuario, recibe imágenes de la cámara, decide qué placa procesar y envía coordenadas/comandos al robot.
- Robot SCARA: controlado por una placa Arduino + RAMPS (firmware propio). Recibe coordenadas y comandos de la PC y ejecuta movimientos.
- Caja lavadora: controlada por una placa (Arduino + RAMPS) con lógica local para maniobrar sus grippers, bombas y servos; se comunica con la PC/robot mediante un ESP32 (nodo de I/O).
- Cámara: conecta con la PC y ejecuta el código de detección (YOLO v8m).
La PC orquesta el proceso; los microcontroladores ejecutan la lógica local mínima (control de motores, drivers, lectura de sensores) y actúan a nivel de actuadores cuando reciben órdenes.

### 11.2 Protocolos y señales

Resumen de los protocolos y buses utilizados:
- TCP / UART: la comunicación entre la PC y el firmware del robot se establece vía USB– Serial (conexión serie sobre USB). Asimismo se utiliza TCP para la comunicación con el código de la cámara según la implementación actual.
- I²C: bus local usado internamente en el robot para encoders / sensores (AS5600 y multiplexor TCA9548A).
- Señales GPIO: entre el ESP32 y el Arduino de la caja se usan pines digitales directos para comandos sencillos (p. ej. “cerrar gripper”, “iniciar ciclo”).
- Sin handshake: actualmente no existe protocolo de ACK/handshake formal entre SCARA ↔ lavadora; la comunicación es mayoritariamente unidireccional y basada en comandos simples.
Nota: cuando se menciona “UART/TCP” se refiere a los canales usados en la práctica: comunicación serie sobre USB para microcontroladores y TCP/Socket para servicios de visión si están desplegados en procesos distintos.

### 11.3 Topología física del cableado

La topología física implementada es la siguiente:
- PC ↔ Robot: cable USB (USB–Serial) conectado a la placa Arduino del robot (longitud típica en bancada).
- PC ↔ Cámara: conexión directa de la cámara a la PC (USB o flujo de red según la configuración del software de visión).
- ESP32 ↔ Caja lavadora (Arduino): conexión por pines (GPIO) entre ESP32 y Arduino de la lavadora.
- Cableado de potencia: cada subsistema dispone de su fuente (SCARA: 12 V 15 A; lavadora: 12 V 20 A y 5 V 20 A) y líneas de alimentación separadas; el control de señales usa las conexiones descritas arriba.

### 11.4 Flujo operativo (secuencia normal de trabajo)

Flujo ideal (paso a paso) tal como se ejecuta en el prototipo:
1. El operario pulsa Play en la interfaz de la PC.
2. La PC inicia el programa de visión; la cámara escanea las zonas predefinidas.
3. Si la cámara detecta QRs / placas, la PC selecciona una (prioridad según criterio) y envía las coordenadas de pick al robot.
4. El robot recibe las coordenadas y ejecuta la rutina de desplazamiento para agarrar la placa.
5. El robot traslada la pieza hasta la zona de transferencia frente a la lavadora y se posiciona en el punto de entrega.
6. El robot espera unos segundos y envía señal a la lavadora (vía ESP32) para que cierre su gripper y asegure la pieza.
7. Una vez confirmado el agarre (por tiempo/retardo en el prototipo), el robot abre su gripper y se retira.
8. La PC envía la orden de inicio de ciclo a la lavadora; la lavadora ejecuta el ciclo configurado (aspersión, rotación, inmersión).
9. Al finalizar el ciclo, la lavadora envía una señal de finalización a la PC/robot.
10. El robot regresa, recoge la pieza y la deposita en la ubicación final predefinida.
11. El sistema vuelve a modo escaneo; si no se detectan más placas en el tiempo límite la rutina finaliza.

### 11.5 Lógica de orquestación

La PC actúa como maestro: toma decisiones de alto nivel (qué pieza procesar, cuándo iniciar ciclo de lavado).
- Los Arduinos ejecutan lógica de control local (mover ejes, homing, control de servos) y rutinas sencillas de seguridad.
- El ESP32 actúa como puente de señal entre la PC/robot y la electrónica de la lavadora (pines digitales para comandos).

En la implementación actual la “lógica de orquestación” está centralizada en la PC; los microcontroladores no implementan una máquina de estados distribuida con confirmaciones formales (ACK).

### 11.6 Tiempos y tolerancias temporales

- La integración está diseñada para tolerar variaciones de segundos en la sincronización de eventos.
- Latencias de red/puerto serie no impactan el proceso si son del orden de decenas a cientos de milisegundos.
- El comportamiento del sistema es robusto frente a pequeñas desincronizaciones: una orden iniciada “unos segundos antes o después” no perjudica la secuencia global.

### 11.7 Manejo de errores y políticas operativas

Actualmente:
- Detección de ausencia de detecciones (visión): si la cámara no detecta objetos durante un tiempo prefijado la rutina finaliza.
- Fallo de agarre: no existe sensor que confirme agarre en el prototipo, por lo que se asume que el diseño del gripper elimina la posibilidad de fallo; si ocurriera, el sistema no lo detectaría automáticamente.
- Bomba sin presión: la lavadora debe detener su rutina si la bomba no alcanza presión; esto provoca parada del sistema de lavado y la rutina global.
- Reintentos y timeouts: algunos subsistemas incorporan reintentos automáticos y timeouts locales; no existe un framework centralizado de manejo de excepciones ni registro de eventos.

### 11.8 Handshake, ACK y trazabilidad

- En el estado actual no existe protocolo de handshake ni confirmaciones formales entre SCARA ↔ lavadora ↔ PC.
- No se registran logs de operación ni de eventos (no hay trazabilidad automatizada de acciones, IDs de pieza ni timestamps).

### 11.9 Interfaz de usuario y control

- Interfaz principal: GUI en PC con botones y controles para Home, Start/Play, Stop, y jog manual.
- Existe un botón de parada en la interfaz del robot y de la caja en la GUI.
- Hay un control físico general (zapatilla) que corta alimentación a todos los subsistemas (interruptor de alimentación física).

### 11.10 Calibración y parámetros configurables

- Calibración visión ↔ robot: se usa calibración manual por offsets (se alinean QRs y se ajustan offsets en software).
- Parámetros configurables online: tiempos de aspersión, tiempo de inmersión, velocidad y aceleración de motores, perfiles de movimiento; estos se ajustan desde la interfaz y se aplican en tiempo de ejecución.
- No existe, por el momento, un registro persistente de versiones de firmware; la última versión del código está corriendo en el sistema actual.

### 11.11 Logging, trazabilidad y versiones

- Logging: actualmente no se registran logs estructurados.

- Trazabilidad de piezas: no se documenta en sistema (por ejemplo: id de ECU, QR y timestamp por ciclo).
- Versionado: no hay control formal de versiones de firmware; se sugiere dejar un campo “versión” para registro (pendiente en el prototipo).

### 11.12 Diagrama de secuencia (texto)

A continuación se presenta una representación textual del diagrama de secuencia entre los actores principales:

1. Operario → PC : Start() (pulsa Play)
2. PC → Cámara : scanArea()
3. Cámara → PC : detections[] (lista de QRs/contenedores detectados)
4. PC → Robot (Arduino) : goto_pick(x,y,z) (coordenadas objetivo)
5. Robot → PC : (no hay ACK formal; movimiento ejecutado localmente)
6. Robot → Lavadora (via ESP32) : positioned_for_transfer (señal indicativa, en la práctica un pin HIGH)
7. Lavadora → Robot : (no hay ACK) — espera tiempo fijo y cierra gripper local
8. Robot : open_gripper(); retreat()
9. PC → Lavadora (via ESP32) : start_wash(cycle_params)
10. Lavadora → PC : done (señal de fin de ciclo, en la práctica pin HIGH o mensaje simple)
11. PC → Robot : goto_pick_return()
12. Robot : recoge y deposita la pieza.

Observación: la ausencia de ACKs formales implica que las “señales” descritas pueden implementarse como pulsos/pines o como mensajes simples, pero no hay confirmación de estado completa entre nodos.

### BLOQUE V – GESTIÓN DEL PROYECTO

### 12. Planificación del Proyecto

### 12.1 Diagrama de Gantt

Se elaboró un diagrama de Gantt que refleja las tareas principales del proyecto (diseño, modelado CAD, fabricación, integración visión, pruebas, documentación y cierre). El diagrama incluye hitos, dependencias y entregables asociados a cada etapa.
Proyecto Final - Diagrama de Gant.xlsx (https://github.com/bellomifede-dot/Proyecto-Final---Lavadora-de-Ecus/blob/main/Proyecto%20Final%20-%20Diagrama%20de%20Gant.xlsx)

### 12.2 Horas estimadas por etapa

Antes de comenzar la ejecución se registraron las horas estimadas por etapa (diseño mecánico, electrónica, visión, integración, ensayos y documentación). La hoja de planificación muestra el reparto de horas por rol y por sprint.

Durante la ejecución se llevó un registro de horas reales invertidas por persona y etapa; los datos se recogieron en formato hoja de cálculo para facilitar el cruce con lo estimado.

Se realizó la comparación entre estimado y real por etapa y por rol, con columnas de variación absoluta y relativa. El resumen muestra acumulados por módulo (mecánica, electrónica, visión, integración y documentación).
Tabla de Horas.xlsx (https://github.com/bellomifede-dot/Proyecto-Final---Lavadora-de-Ecus/blob/main/Tabla%20de%20Horas.xlsx)

### 12.3 Análisis de desvíos

El análisis identifica las causas principales de desvío (iterations de diseño, reemplazos, tiempo en debug de visión) y cuantifica su impacto en horas. Las observaciones permiten priorizar medidas correctivas en futuros proyectos.

Se consolidaron las lecciones aprendidas relacionadas con estimación de tiempos, verificación temprana de componentes críticos y gestión de repuestos. Este documento se incorpora al cierre del proyecto como referencia para próximas iteraciones.

Se registró una estimación inicial de costos agrupada por categorías (mecánica, electrónica, sensores, actuation, mano de obra y contingencias). Esa estimación sirvió de línea base para el control presupuestario.

Todos los gastos reales (facturas, compras, reposiciones y compras de repuesto) se consolidaron en una hoja de control de costos. El archivo incluye notas sobre partidas atípicas (rodamientos, drivers extra, piezas reemplazadas).
Gestión y Control de Costos del Proyecto.pdf (https://github.com/bellomifede-dot/Proyecto-Final---Lavadora-de-Ecus/blob/main/Gesti%C3%B3n%20y%20Control%20de%20Costos%20del%20Proyecto.pdf)

### BLOQUE VI – RESULTADOS Y CONCLUSIONES 15. Ensayos y Pruebas Realizadas

En esta sección se listan y resumen los ensayos ejecutados para validar los requisitos del sistema. El protocolo completo, los procedimientos paso a paso, las tablas de captura de datos y los criterios de aceptación se encuentran en el documento de ensayos del proyecto.

Ensayos realizados (resumen):
- 15.1 Ensayo de repetibilidad del SCARA — prueba posicional repetida en puntos representativos del workspace, registro de desviaciones en X, Y y Z. Ver procedimiento y criterios en el anexo de ensayos.
- 15.2 Ensayo de carga máxima — verificación de integridad estructural y funcionamiento de los actuadores bajo cargas crecientes hasta el rango objetivo de diseño.
- 15.3 Ensayo del sistema de aspersión — activación de bomba, control on/off y evaluación de cobertura y tiempos de aspersión. Presión nominal de la bomba: 2.7–4.1 bar (bomba de inyectores).
- 15.4 Ensayo del sistema ultrasónico — pruebas demostradoras con batea + motor desbalanceado; no se alcanzaron condiciones ultrasónicas activas con el arreglo usado (se documenta como demostrador mecánico).
- 15.5 Ensayo de integración completa — ciclo completo desde detección por visión → pick & place → transferencia a lavadora → ciclo de lavado → devolución. Registro de tiempos de ciclo y tasa de éxito por pieza.

Los registros detallados, planillas de medición y las hojas con los timestamps y resultados crudos están en el fichero Ensayos.pdf (https://github.com/bellomifede-dot/Proyecto-Final---Lavadora-de-Ecus/blob/main/Ensayos.pdf)

### 16. Resultados y Análisis

### 16.1 Resultados obtenidos

- Repetibilidad del SCARA: las pruebas realizadas muestran que el manipulador cumple con la repetibilidad de referencia requerida en el diseño (orden de 1 mm en condiciones de prueba), lo que permite la operación de pick & place con la geometría autocentrante del gripper. (Datos crudos y protocolo: Ensayos.docx).
- Carga y estructura: las verificaciones estáticas y funcionales confirmaron que la estructura y las transmisiones (con las reducciones definidas) sostienen de forma confiable la carga objetivo (diseño sobre-dimensionado para dar margen). Detalles de cálculos y supuestos están en la sección mecánica del informe principal.
- Sistema de aspersión: la bomba (on/off) y los inyectores funcionaron conforme a lo esperado dentro del rango de presión medido (2.7–4.1 bar). Se validó la secuencia de aspersión en ambas caras mediante rotación del soporte.
- Ultrasonido: la implementación prototipo es demostradora: el motor desbalanceado no alcanza frecuencias ultrasónicas útiles; por tanto, la limpieza por ultrasonido no fue verificada en condiciones reales de cavitación. Se documenta la necesidad de transductores y electrónica dedicada para una implementación efectiva.

### 16.2 Comparación con objetivos iniciales

- En cuanto a repetibilidad y manipulación, el sistema cumple con el objetivo de repetibilidad mínima (≈1 mm), por lo que el requisito de manipulación de ECUs se considera alcanzado bajo las condiciones de prueba.
- En limpieza por aspersión, el sistema funciona funcionalmente y cumple la parte de aspersión del proceso; sin embargo, el objetivo de limpieza por ultrasonido no se alcanzó en el prototipo por limitaciones de hardware (transductores/driver).

### 17. Conclusiones y Mejoras Futuras

### 17.1 Conclusiones técnicas

El presente proyecto permitió diseñar, desarrollar e integrar una célula automatizada compuesta por un manipulador tipo SCARA, un sistema de visión artificial y un módulo de lavado orientado a la manipulación y limpieza de placas electrónicas (ECUs). El trabajo abarcó las etapas de concepción, modelado mecánico, selección y montaje de componentes electrónicos, programación de control, integración de visión con inteligencia artificial y validación experimental mediante ensayos específicos.

Desde el punto de vista mecánico, el manipulador desarrollado cumplió con los requerimientos de repetibilidad planteados para la aplicación, logrando una precisión adecuada para operaciones de pick & place sobre piezas de dimensiones reducidas. La arquitectura adoptada, junto con el sistema de reducción por poleas y la compensación de masa en el eje vertical, permitió un desempeño estable y coherente con los cálculos de diseño. El efector final diseñado facilitó la manipulación consistente de las placas, demostrando la correcta correspondencia entre diseño teórico y comportamiento real.

En cuanto al sistema de visión, la implementación basada en detección mediante modelo YOLO permitió identificar y localizar las piezas dentro del campo de trabajo, integrando el procesamiento en una arquitectura centralizada en PC. La calibración por offsets y la comunicación con el controlador del robot posibilitaron cerrar el lazo entre detección y acción, consolidando el flujo automático completo del sistema.

El módulo de lavado validó el funcionamiento del sistema de aspersión dentro de los parámetros definidos, integrándose correctamente con la secuencia general del proceso. La interacción entre robot y caja de lavado, coordinada desde la PC, demostró la viabilidad del esquema de control propuesto y la correcta sincronización entre subsistemas.

En términos de gestión, el proyecto incluyó planificación mediante diagrama de Gantt, estimación y seguimiento de horas de trabajo, así como análisis comparativo entre costos estimados y reales. Este enfoque permitió no solo materializar el desarrollo técnico, sino también evaluar el desempeño del proyecto desde una perspectiva organizacional y económica, integrando criterios de ingeniería y gestión en un mismo marco de trabajo.

En conjunto, el proyecto logró validar el concepto de una célula automatizada para manipulación y lavado de ECUs, integrando mecánica, electrónica, control y visión artificial en una solución funcional de prototipo. La experiencia adquirida evidencia la coherencia entre diseño, implementación y ensayo, y consolida una base técnica sólida para desarrollos posteriores dentro del ámbito de la automatización industrial aplicada.

### 17.2 Propuestas de Mejora

LAVADORA DE ECUS
1. Incorporación de sistema de seguridad para solventes inflamables

Dado que el sistema opera con alcohol isopropílico al 99%, resulta imprescindible, en una versión industrial, incorporar:

- Ventilación forzada interna con extracción controlada.
- Separación física entre compartimento húmedo y compartimento eléctrico.
- Sensores de apertura de tapa con enclavamiento de seguridad.
- Sistema de corte automático ante sobrecorriente o falla.

Esto incrementaría significativamente el nivel de seguridad operativa.

2. Implementación de recirculación y filtrado del fluido

El sistema actual utiliza tanque abierto sin filtrado. Se propone:

- Sistema cerrado con retorno.
- Filtro de partículas en línea.
- Control de nivel de líquido.
- Regulador de presión para estabilizar los 3 bar.

Esto permitiría mejorar la eficiencia del consumo de solvente y la repetibilidad del proceso.

3. Mejora estructural y hermetización

Para aproximarse realmente a un grado de protección IP68, sería necesario:

- Incorporar juntas de goma perimetrales.
- Uso de prensaestopas industriales.
- Sellado mecánico con tornillería en lugar de adhesivo.
- Bandeja de contención para derrames.
4. Optimización del sistema ultrasónico

El diseño actual contempla 40 kHz como especificación proyectada. Para una versión mejorada se propone:

- Generador ultrasónico dedicado de potencia controlada (≈100–150 W).
- Control de temperatura del baño (40–50 °C).
- Sensor térmico con corte automático.
- Sistema de secado posterior (aire caliente o soplado forzado).

5. Sensores adicionales y monitoreo

Se propone incorporar:

- Sensor de nivel de líquido.
- Sensor de temperatura.
- Sensor de corriente en bomba.
- Señalización luminosa de estado (ciclo en curso, error, finalización).

Esto permitiría convertir el prototipo en una máquina con características industriales.

6. Mejora del sistema de sujeción

El sistema actual funciona correctamente, pero podría optimizarse mediante:

- Control de fuerza de sujeción.
- Revestimiento con material antiestático.
- Sistema de drenaje en el soporte.
- Diseño modular intercambiable según tipo de ECU.

ROBOT SCARA
1. Incorporación de encoders absolutos

Actualmente el posicionamiento depende de pasos de motor y homing. Se propone:

- Incorporar encoders absolutos o incrementales en cada eje.
- Implementar lazo cerrado de control.

Esto permitiría mayor precisión y reducción de error acumulativo.

2. Optimización estructural

Si bien el sistema está sobredimensionado en torque, podrían mejorarse:

- Rigidez de los brazos.
- Uso de aluminio mecanizado en lugar de piezas impresas.
- Reducción de peso en eslabones para disminuir inercia.

Esto permitiría mayores velocidades sin comprometer precisión.

3. Mejora del sistema de visión

Se podría optimizar mediante:

- Cámara industrial con obturador global.
- Iluminación controlada LED.
- Uso de algoritmos de detección más robustos.

4. Implementación de seguridad industrial

El SCARA podría incorporar:

- Zona de trabajo delimitada.
- Sensores de colisión.
- Sistema de parada controlada.
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

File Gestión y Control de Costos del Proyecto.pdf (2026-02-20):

# Gestión y Control de Costos del Proyecto

## Objetivo del análisis económico

El presente documento tiene como finalidad documentar el análisis económico del proyecto, incluyendo la estimación inicial de costos, el registro de los costos reales incurridos durante el desarrollo, y la comparación entre ambos valores.

La gestión de costos permite evaluar la viabilidad técnica–económica del sistema desarrollado, analizar desviaciones presupuestarias y extraer conclusiones relevantes para futuros desarrollos o escalado industrial.

## Metodología de estimación de costos

Previo al inicio de la etapa de construcción, se realizó una estimación preliminar de costos basada en:

- Precios de mercado de componentes electrónicos y mecánicos.
- Presupuestos de proveedores locales.
- Estimación de horas de trabajo de impresión 3D.

La estimación incluyó tanto costos directos (materiales y componentes) como costos indirectos (herramientas, servicios, impresión 3D, etc.).

Para estructurar el análisis, los costos fueron agrupados en las siguientes categorías:

- Componentes mecánicos (perfiles, rodamientos, tornillería, piezas impresas).
- Componentes electrónicos (motores, drivers, microcontroladores, fuentes).
- Sistema de visión.
- Cableado y accesorios.
- Mano de obra 3d.
- Costos imprevistos.

## Costos estimados

Los costos estimados fueron calculados antes de la adquisición de los componentes y reflejan la planificación económica del proyecto.

Cada ítem fue presupuestado considerando:

- Cantidad requerida.
- Precio unitario estimado.
- Costo total estimado por ítem.
- Subtotal por categoría.

El total estimado del proyecto corresponde a la suma de todos los subtotales por categoría.

Parte mecanica
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

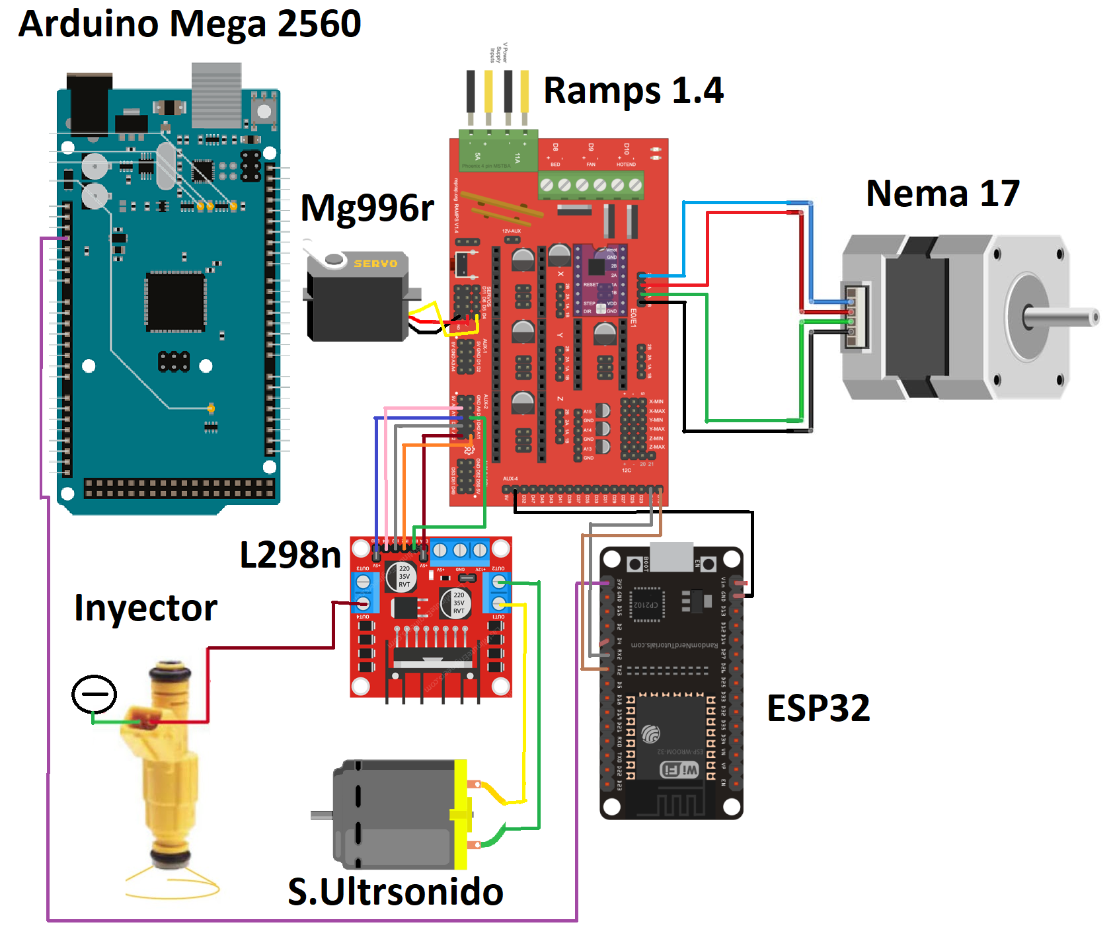
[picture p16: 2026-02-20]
Esquemas Electronicos/Esquema Lavadora.png

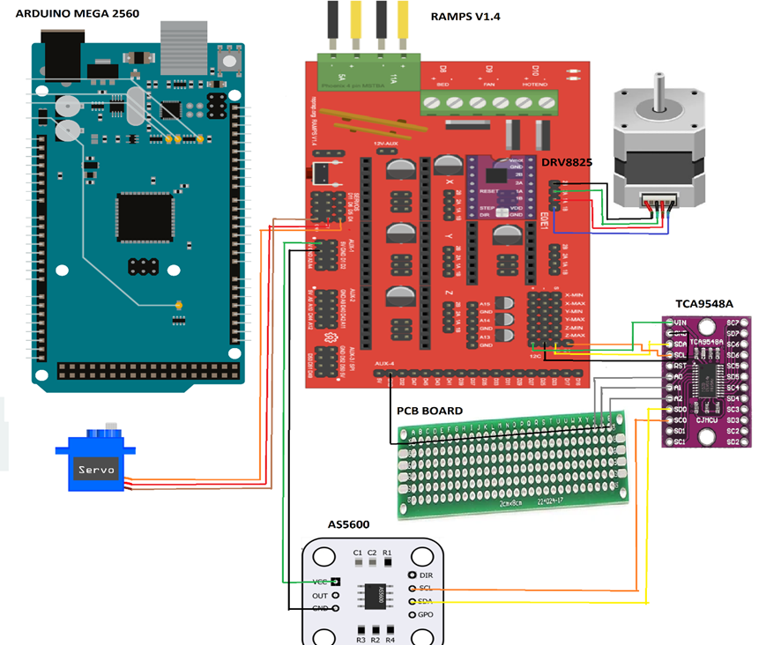
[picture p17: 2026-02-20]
Esquemas Electronicos/Esquema Scara.png

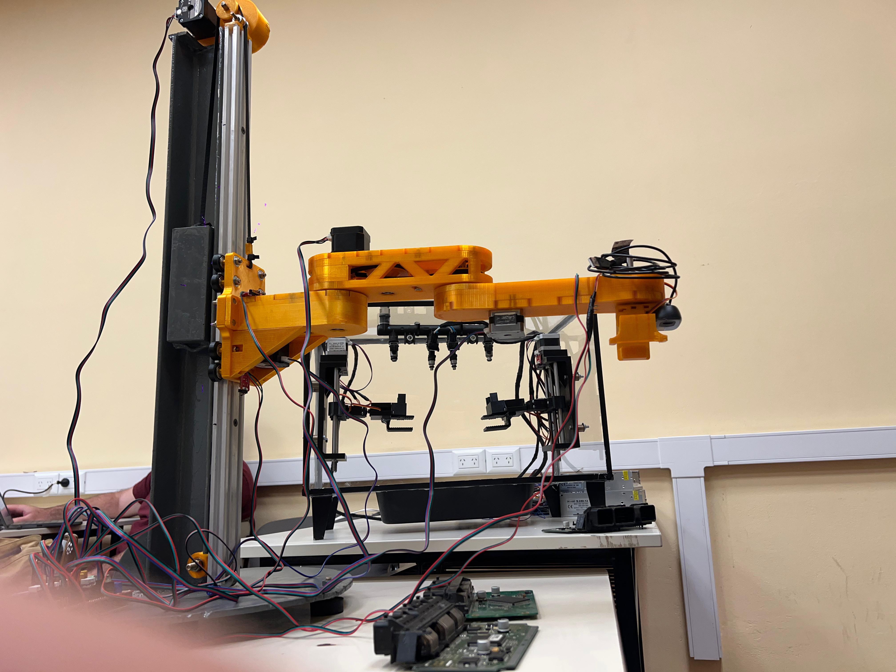
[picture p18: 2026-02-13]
Fotos y Videos/SCARA + Lavadora de ECUs 3.jpeg

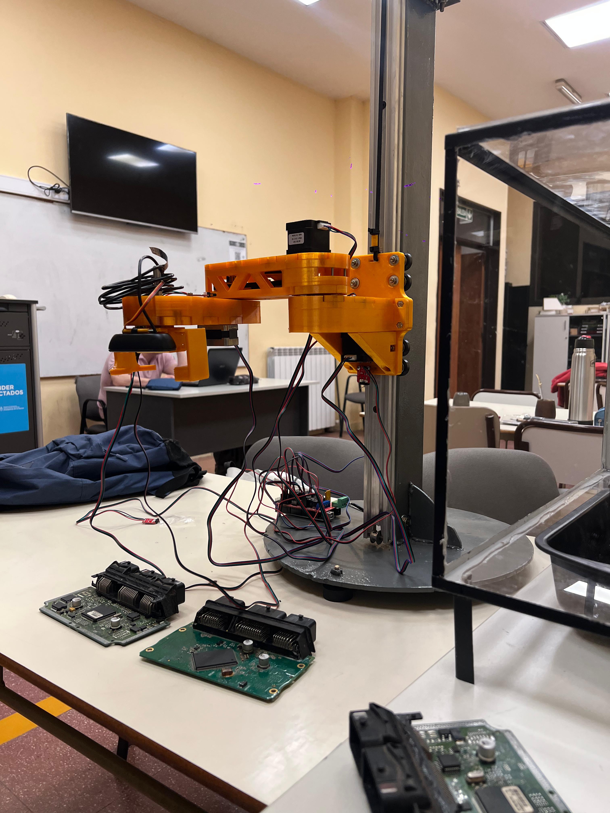
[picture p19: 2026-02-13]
Fotos y Videos/Robot SCARA 2.jpeg

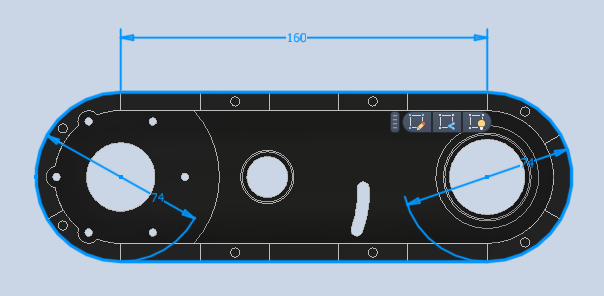
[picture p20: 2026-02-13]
Fotos y Videos/Captura de pantalla 2025-10-23 170648.png

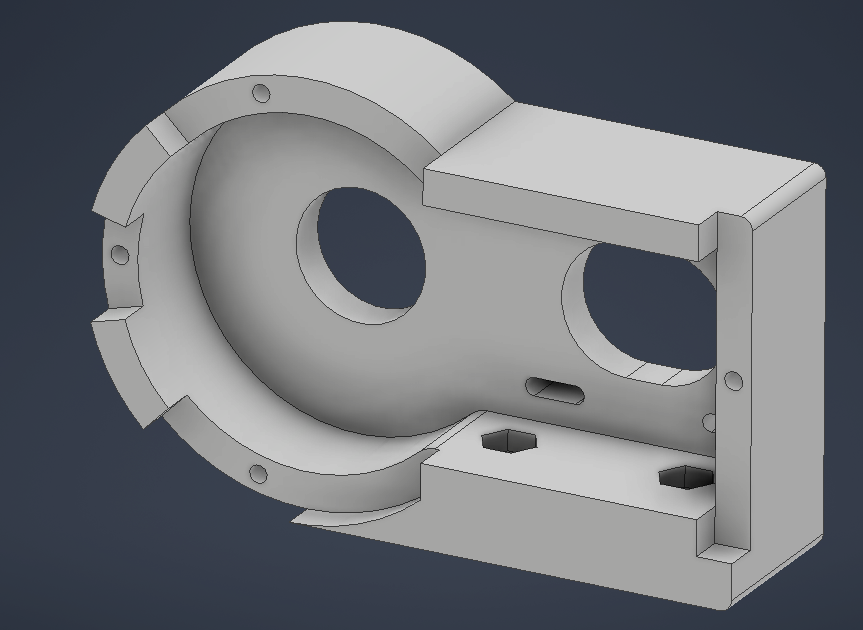
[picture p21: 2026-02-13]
Fotos y Videos/Captura de pantalla 2025-07-23 194242.png

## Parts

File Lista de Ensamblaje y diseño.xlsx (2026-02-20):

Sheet: Costos
 | Material | Cantidad
Eje Z - Engranaje para gt2 | ISO 4014 Bulon M8 x 50MM | 1
 | ISO 4032 Tuerca M8 | 1
 | ISO 7089 Arandela 8mm | 2
 | Engranaje insertado en UPN | 1 | Impreso en 3d
 | Buje para UPN | 1 | Impreso en 3d
 | Rodamiento 688 ZZ | 2
Eje Z - Vslot para gt2 | ISO 4014 Bulon M5 x 35mm | 1
 | ISO 4032 Tuerca M5 | 1
 | ISO 7093 A Arandela 5mm | 2
 | Vslot | 1
Vslot para soporte(x8) | Buje plástico para Vslot | 8 | Impreso en 3d
 | Rueda Vslot | 8
 | ISO 4014 Bulon M5 x 35mm | 8
 | ISO 4032 Tuerca M5 | 8
 | ISO 7093 A Arandela 5mm | 12
Engranaje - Eje z | Engranaje cónico eje Z | 1 | Impreso en 3d
 | Cono interno para engranaje | 1 | Impreso en 3d
 | Rodamiento 608zz | 2
 | ISO 4017 Bulon M3 x 12mm | 2
 | ISO 4032 Tuerca M3 | 2
 | Perno de posición ISO 2338 8mmX60mm | 2
Caja reductora - Eje z | Caja reductora eje Z | 1 | Impreso en 3d
 | Tapa de caja reductora | 1 | Impreso en 3d
 | ISO 7045 Tornillo phillip M3 x10mm | 4
 | Inserto para rosca M3 (largo) | 4
 | Polea Gt2 16 Dientes | 1
 | ISO 7045 Tornillo Phillip M3 X 10mm | 4
Tensor de polea - Primer Segmento | ISO 4017 Bulon M3 x 20mm | 1
 | ISO 4032 Tuerca M3 | 2
 | ISO 7089 A Arandela 3mm | 1
 | Polea Lisa gt2 para eje de 3mm | 1
Primer Segmento | Soporte primer segmento | 1 | Impreso en 3d
 | Parte inferior - Primer Segmento | 1 | Impreso en 3d
 | Parte superior - Primer Segmento | 1 | Impreso en 3d
 | Engranaje Doble | 1 | Impreso en 3d
 | Engranaje Simple | 1 | Impreso en 3d
 | Rodamiento 625zz | 3
 | Rodamiento 6806 | 1
 | Rodamiento Axial 51107 | 1
 | Perno de posición ISO 2338 8mmX40mm | 1
 | Perno de posición ISO 2338 8mmX60mm | 1
 | Polea Gt2 16 Dientes | 1
 | ISO 4017 Bulon M5 x 25mm | 4
 | ISO 4032 Tuerca M5 | 4
 | ISO 7089 A Arandela 5mm | 4
 | ISO 7045 Tornillo phillip M3 x8mm | 6
 | Inserto para rosca M3 (largo) | 6
 | ISO 4017 Bulon M4 x 40mm | 4
 | ISO 4032 Tuerca M4 | 4
 | ISO 7045 Tornillo Phillip M3 X 12mm | 4
Segundo Segmento | Joint -Primer segmento | 1 |  | Robot SCARA
 | Parte inferior - Segundo Segmento | 1
 | Parte superior -Segundo Segmento | 1
 | Engranaje Doble | 1 |  | Componente/Descripción | Cantidad | Unidad | Precio U | Precio total
 | Engranaje Simple - Segundo Segmento | 1 |  | Mecanica:
 | Rodamiento 625zz | 3 |  | Perfil Aluminio 2040 | 1 | metro | $26950.00 | $26950.00
 | Rodamiento 6805 | 1 |  | V Slots 5mm | 13 | u | $1896.62 | $24656.06
 | Rodamiento Axial 51106 | 1 |  | Poleta GT2 16 Dientes | 4 | u | $3747.50 | $14990.00
 | Perno de posición ISO 2338 8mmX40mm | 1 |  | Correas GT2 6mm | 9 | u | $5180.00 | $46620.00
 | Perno de posición ISO 2338 8mmX60mm | 1 |  | Tornilleria: Bulones Arandelas Tuercas | - | - | - | $98366.77
 | Polea Gt2 16 Dientes | 1 |  | Cable piel de serpiente por metro (3mm 5mm 8mm 12mm) | 4 | u | $7635.75 | $30543.00
 | ISO 7045 Tornillo phillip M3 x8mm | 8 |  | Termocontraible (6mm 8mm 12mm 14mm) | 4 | u | $2239.75 | $8959.00
 | Inserto para rosca M3 (largo) | 8 |  | Rodamientos 625 | 9 | u |  | ↓
 | ISO 4017 Bulon M4 x 40mm | 4 |  | Rodamientos 6805 | 2 | u |  | ↓
 | ISO 4032 Tuerca M4 | 10 |  | Rodamientos 290 | 2 | u |  | $171000.00
 | ISO 7045 Tornillo phillip M3 x12mm | 4 |  | Electronica: | 1
 | ISO 7045 Tornillo phillip M4 x16mm | 6 |  | Arduino Mega 2560 | 1 | u | $29799.00 | $29799.00
 |  |  |  | Ramps 1.4 | 2 | u | $6944.00 | $13888.00
 |  |  |  | Fuente 12v 15A | 1 | u | $18685.00 | $18685.00
 |  |  |  | Motores Nema 17 Alto torque 4.3 kgcm | 3 | u | $17900.00 | $53700.00
 |  |  |  | Motor Nema 17 Pancake 1.8 kgcm | 1 | u | $15320.00 | $15320.00
 |  |  |  | Driver pololu DRV8825 | 6 | u | $3648.33 | $21889.98
 |  |  |  | Servomotor SG90 | 1 | u | $3499.00 | $3499.00
 |  |  |  | Finales de carrera microswitch | 5 | u | $2991.00 | $14955.00
 |  |  |  | Cable motor para motores Nema x 1 metro | 9 | u | $3200.00 | $28800.00
 |  |  |  | Impresión 3D
 |  |  |  | Filamento PETG Ambar 1 kg | 2 | u | $20199.00 | $40398.00
 |  |  |  | Insertos 3D para rosca M3 X 100u | 1 | u | $63809.00 | $63809.00
 |  |  |  | Costo de Impresión piezas pequeñas | - | - |  | $78800.00
 |  |  |  | Costo de Impresión piezas grandes | - | - |  | $35000.00
 |  |  |  |  |  | Subtotal |  | $840627.81
 |  |  |  | Visión Artificial
 |  |  |  | Componente/Descripción | Cantidad | Unidad | Precio U | Precio total
 |  |  |  | Camara Logitech 270 (720p) | 1 | u | $41998.00 | $41998.00
 |  |  |  |  |  | Subtotal |  | $41998.00
 |  |  |  | Lavadora de Ecus
 |  |  |  | Componente/Descripción | Cantidad | Unidad | Precio U | Precio total
 |  |  |  | Motores Nema 17 | 2 | u | $16000.00 | $32000.00
 |  |  |  | Servomotores MG946R | 4 | u | $9450.00 | $37800.00
 |  |  |  | Arduino Mega 2560 | 1 | u | $29350.00 | $29350.00
 |  |  |  | Acoples flexibe 8mm | 4 | u | $5829.00 | $23316.00
 |  |  |  | Fuente 5v 20A | 1 | u | $24541.00 | $24541.00
 |  |  |  | Fuente 12v 20A | 1 | u | $26964.00 | $26964.00
 |  |  |  | Varilla Templada Rectificada 8mm 1 metro | 2 | u | $21519.00 | $43038.00
 |  |  |  | Tuerca para Varilla 8mm | 2 | u | $5000.00 | $10000.00
 |  |  |  | Varilla Roscada 8mm | 2 | u | $18913.00 | $37826.00
 |  |  |  | Rodamientos Lineales 8mm | 4 | u | $2750.00 | $11000.00
 |  |  |  | Ramps 1.4 | 1 | u | $5000.00 | $5000.00
 |  |  |  | Drvies Pololu DRV8825 | 2 | u | $6300.00 | $12600.00
 |  |  |  | Cable Motor Nema17 150cm | 6 | u | $7000.00 | $42000.00
 |  |  |  | Finales de Carrera | 2 | u | $3000.00 | $6000.00
 |  |  |  | Placa Acrilico Transparente 60x40x2 | 6 | u | $20106.00 | $120636.00
 |  |  |  | Módulo L298N | 1 | u | $5000.00 | $5000.00
 |  |  |  | Impresiones 3D | 1 | u | $80000.00 | $80000.00
 |  |  |  |  |  | Subtotal |  | $547071.00
 |  |  |  |  |  | Costo total |  | $1429696.81

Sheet: Ensamblaje
Eje Z - Engranaje para gt2
Lista de componentes a comprar | Cantidad | Precio | Comentarios
ISO 4014 Bulon M8 x 50MM | 1
ISO 4032 Tuerca M8 | 1
ISO 7089 Arandela 8mm | 2 |  | ISO 4032 Norma de Arandelas altura normal
Engranaje insertado en UPN | 1 |  | impreso en 3d
Buje para UPN | 1 |  | impreso en 3d
Rodamiento 688 ZZ | 2
Ensamblaje:
Eje Z - Vslot para gt2
Lista de componentes a comprar | Cantidad | Precio | Comentarios
ISO 4014 Bulon M5 x 35mm | 1 |  | ISO 4014 Norma de Bulones con principio liso y rosca al final
ISO 4032 Tuerca M5 | 1 |  | ISO 4032 Norma de Tuercas altura normal
ISO 7093 A Arandela 5mm | 2 |  | ISO 7093 A Norma de arandelas de diametro exterior mas grande
Vslot | 1
Ensamblaje:
Vslot para soporte
Lista de componentes de ensamblaje | Cantidad | Precio | Comentarios
Buje plástico para Vslot | 8 |  | Impreso en 3d
Rueda Vslot | 8
ISO 4014 Bulon M5 x 35mm | 8 |  | ISO 4014 Norma de Bulones con principio liso y rosca al final
ISO 4032 Tuerca M5 | 8 |  | ISO 4032 Norma de Tuercas altura normal
ISO 7093 A Arandela 5mm | 12 |  | ISO 7093 A Norma de arandelas de diametro exterior mas grande
Ensamblaje:
Engranaje 1 - Eje Z
Lista de componentes de ensamblaje | Cantidad | Precio | Comentarios
Engranaje cónico 1 eje Z | 1 |  | Impreso en 3d
Cono interno para engranaje 1 | 1 |  | Impreso en 3d
Rodamiento 608zz | 2
ISO 4017 Bulon M3 x 16mm | 2 |  | ISO 4017 Norma de Bulones con rosca completa
ISO 4032 Tuerca M3 | 2 |  | ISO 4032 Norma de Tuercas altura normal
ISO 7089 A Arandela 3mm | 2 |  | ISO 7089 Norma de Arandelas altura normal
Perno de posición ISO 2338 8mmX60mm | 2 |  | ISO 2338 Norma de pernos de posición (tambien puede ser norma ISO 8734 DIN7 y DIN 6325)
Engranaje 2 - Eje Z
Lista de componentes de ensamblaje | Cantidad | Precio | Comentarios
Engranaje cónico 2 eje Z | 1 |  | Impreso en 3d
Cono interno para engranaje 2 | 1 |  | Impreso en 3d
ISO 4017 Bulon M3 x 16mm | 2 |  | ISO 4017 Norma de Bulones con rosca completa
ISO 4032 Tuerca M3 | 2 |  | ISO 4032 Norma de Tuercas altura normal
ISO 7089 A Arandela 3mm | 2 |  | ISO 7089 Norma de Arandelas altura normal
Caja Reductora - Eje Z
Lista de componentes de ensamblaje | Cantidad | Precio | Comentarios
Caja reductora eje Z | 1 |  | Impreso en 3d
Tapa de caja reductora | 1 |  | Impreso en 3d
ISO 7045 Tornillo phillip M3 x10mm | 4 |  | ISO 7045 Norma de tornillos philips
Inserto para rosca M3 (largo) | 4 |  | Insertos para rosca M3 para fijar en impresión 3d
Polea Gt2 16 Dientes | 1 |  | Polea para nema 17 (16 dientes)
ISO 7045 Tornillo phillip M3 x10mm | 4 |  | ISO 7045 Norma de tornillos philips
Tensor de polea - Primer Segmento
Lista de componentes de ensamblaje | Cantidad | Precio | Comentarios
ISO 4017 Bulon M3 x 20mm | 1 |  | ISO 4017 Norma de Bulones con rosca completa
ISO 4032 Tuerca M3 | 2 |  | ISO 4032 Norma de Tuercas altura normal
ISO 7089 A Arandela 3mm | 1 |  | ISO 7089 Norma de Arandelas altura normal
Polea Lisa gt2 para eje de 3mm | 1
Primer Segmento
Lista de componentes de ensamblaje | Cantidad | Precio | Comentarios
Soporte primer segmento | 1 |  | Impreso en 3d
Parte inferior - Primer Segmento | 1 |  | Impreso en 3d
Parte superior - Primer Segmento | 1 |  | Impreso en 3d
Engranaje Doble | 1 |  | Impreso en 3d
Engranaje Simple | 1 |  | Impreso en 3d
Rodamiento 625zz | 3 |  | ISO 4017 Norma de Bulones con rosca completa
Rodamiento 6805 | 1 |  | ISO 4032 Norma de Tuercas altura normal
Rodamiento Axial 51106 | 1 |  | ISO 7089 Norma de Arandelas altura normal
Perno de posición ISO 2338 8mmX40mm | 1 |  | ISO 2338 Norma de pernos de posición (tambien puede ser norma ISO 8734 DIN7 y DIN 6325)
Perno de posición ISO 2338 8mmX60mm | 1 |  | ISO 2338 Norma de pernos de posición (tambien puede ser norma ISO 8734 DIN7 y DIN 6325)
Polea Gt2 16 Dientes | 1 |  | Polea para nema 17 (16 dientes)
ISO 4017 Bulon M5 x 25mm | 4 |  | ISO 4017 Norma de Bulones con rosca completa
ISO 4032 Tuerca M5 | 4 |  | ISO 4032 Norma de Tuercas altura normal
ISO 7089 A Arandela 5mm | 4 |  | ISO 7089 Norma de Arandelas altura normal
ISO 7045 Tornillo phillip M3 x8mm | 6 |  | ISO 7045 Norma de tornillos philips
Inserto para rosca M3 (largo) | 6 |  | Insertos para rosca M3 para fijar en impresión 3d
ISO 4017 Bulon M4 x 40mm | 4 |  | ISO 4017 Norma de Bulones con rosca completa
ISO 4032 Tuerca M4 | 4 |  | ISO 4032 Norma de Tuercas altura normal
ISO 7045 Tornillo phillip M3 x12mm | 4 |  | ISO 7045 Norma de tornillos philips
Segundo Segmento
Lista de componentes de ensamblaje | Cantidad | Precio | Comentarios
Joint -Primer segmento | 1 |  | Impreso en 3d
Parte inferior - Segundo Segmento | 1 |  | Impreso en 3d
Parte superior -Segundo Segmento | 1 |  | Impreso en 3d
Engranaje Doble | 1 |  | Impreso en 3d
Engranaje Simple - Segundo Segmento | 1 |  | Impreso en 3d
Rodamiento 625zz | 3
Rodamiento 6805 | 1
Rodamiento Axial 51106 | 1
Perno de posición ISO 2338 8mmX40mm | 1 |  | ISO 2338 Norma de pernos de posición (tambien puede ser norma ISO 8734 DIN7 y DIN 6325)
Perno de posición ISO 2338 8mmX60mm | 1 |  | ISO 2338 Norma de pernos de posición (tambien puede ser norma ISO 8734 DIN7 y DIN 6325)
Polea Gt2 16 Dientes | 1 |  | Polea para nema 17 (16 dientes)
ISO 7045 Tornillo phillip M3 x8mm | 8 |  | ISO 7045 Norma de tornillos philips
Inserto para rosca M3 (largo) | 8 |  | Insertos para rosca M3 para fijar en impresión 3d
ISO 4017 Bulon M4 x 40mm | 4 |  | ISO 4017 Norma de Bulones con rosca completa
ISO 4032 Tuerca M4 | 10 |  | ISO 4032 Norma de Tuercas altura normal
ISO 7045 Tornillo phillip M3 x12mm | 4 |  | ISO 7045 Norma de tornillos philips
ISO 7045 Tornillo phillip M4 x16mm | 6 |  | ISO 7045 Norma de tornillos philips

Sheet: Mecanica
Arandelas estrechas ISO 7093
ISO 7093 A - ST 5 - 140 HV | 14
Arandelas comunes ISO 7089
ISO 7089 - 3 | 8
ISO 7089 - 4 | 12
ISO 7089 - 5 | 4
ISO 7089 - 6 | 2
ISO 7089 - 8 | 2
Tuercas comunes ISO 4032
ISO 4032 - M3 | 12
ISO 4032 - M4 | 20
ISO 4032 - M5 | 12
ISO 4032 - M6 | 3
ISO 4032 - M8 | 1
Bulones mitad roscados ISO 4014
ISO 4014 - M3 x 20 | 4
ISO 4014 - M5 x 35 | 9
ISO 4014 - M6 x 30 | 2
ISO 4014 - M8 x 50 | 1
Bulones con rosca completa ISO 4017
ISO 4017 - M3 x 16 | 4
ISO 4017 - M4 x 40 | 8
ISO 4017 - M5 x 25 | 4
Tornilos phillip ISO 7045
ISO 7045 - M3 x 8 - 4.8 - H | 22
ISO 7045 - M3 x 10 - 4.8 - H | 4
ISO 7045 - M4 x 16 - 4.8 - H | 12
Rodamientos SKF 2Z
SKF 6805 2Z 25x37x7 | 3
SKF 290 2Z | 2
SKF 625 2Z | 9
Pernos de posición ISO 2338
ISO 2338 - 8mm h8 x 60 | 3
ISO 2338 - 8mm h8 x 40 | 2
Bulones | $35.234
Rulemanes 625 y 688 | $171.000
Rulemanes 6805
Bulones 4014

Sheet: Electronica
Arduino Mega 2560 | 1 | Comprado
Nema 17 Pancake | 1 | Comprado
Servomotor SG90 | 1 | Comprado
Fuente 12v | 1 | Comprado
Nema 17 Altotorque | 3 | Comprado
Shield Ramps 1.5 Driver Pololu Arduino Mega Impresora 3d Cnc | 1 | Comprado
Drivers8825 | 6 | Comprado
Perfil Alumino 2040 | 1 metro | Comprado
V slots 5mm | 9 | Comprado
Polea GT2 16 Dientes | 4 | Comprado
Polea GT2 Lisa Eje 3mm | 4 | Comprado
Inserto 3D - M3 (Largo) | 26 | Comprado
Micro Switch | 4 | Comprado
Tira de correa GT2 | 1,5 metros
Correa GT2 X 200mm (100T) | 4
Correa GT2 X 300mm (150T) | 1
Correa GT2 X 400mm (200T) | 1

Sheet: Imprimir
 | Nº de pieza | Miniatura | Cantidad
Eje Z | Buje 1 para UPN |  | 1
 | GT2 Clip |  | 4
 | Engranaje insertado en pin |  | 1
 | Tapa de caja reductora - eje z |  | 1
 | Caja reductora - eje z |  | 1
 | Cono interno - Engranaje 1 eje Z |  | 1
 | Engranaje 1 - eje Z |  | 1
 | Cono interno - Engranaje 2 eje Z |  | 1
 | Engranaje 2 - eje z |  | 1
 | Tapa inferior perfil de aluminio |  | 1
 | Tapa superior perfil de aluminio |  | 1
Primer segmento | Soporte del primer segmento |  | 1
 | Segmento inferior |  | 1
 | Segmento superior |  | 1
 | Buje paraVslot |  | 8
 | Engrajane doble |  | 2
 | Engranaje simple - primer segmento |  | 1
 | Joint - Primer segmento |  | 1
Segundo segmento | Engranaje simple - segundo segmento |  | 1
 | Joint - Segundo segmento |  | 1
 | Segundo segmento - inferior - Shape generator prueba 2 - 40% |  | 1
 | Segundo segmento - superior |  | 1
Tercer Segmento | Engranaje simple - tercer segmento |  | 1
 | Tercer Segmento - inferior |  | 1
 | Tercer segmento - superior |  | 1
 | Filamento PETG AMBAR |  | 1
 | Filamento: |  | $30.000
 | Total Eze: |  | $60.819,62

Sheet: Normas ISO
Tuercas
Característica | Altura Normal (Estándar) | Altura Alta (Reforzada) | Altura Baja (Contratuerca)
Paso Grueso | ISO 4032 (Uso General) | ISO 4033 (Alta Resistencia) | ISO 4035 (Bloqueo)
Paso Fino | ISO 8673 (Anti-vibración) | ISO 8674 (Máxima Exigencia) | ISO 8675 (Bloqueo de Precisión)
Bulones
Característica | Parcialmente Roscado (con vástago liso) | Totalmente Roscado (hasta la cabeza)
Uso General (Grado A/B) | ISO 4014 (Paso Grueso)ISO 8765 (Paso Fino) | ISO 4017 (Paso Grueso)ISO 4018 (Paso Fino)
Uso Rústico (Grado C) | ISO 4016 (Paso Grueso) | (No tiene un equivalente directo y común)
Arandelas
Espesor | Tipo de Arandela | Norma(s) Comunes | Característica Principal de Espesor
Repartir Carga | Plana Normal | ISO 7089 (DIN 125) | Uso estándar, equilibrio de diámetros.
 | Plana Ancha | ISO 7093 (DIN 9021) | Diámetro exterior muy grande.
 | Plana Estrecha | ISO 7092 (DIN 433) | Diámetro exterior pequeño.
Grueso / Reforzado | Para Estructuras | ISO 7415 (DIN 6916) | Mucho más gruesa y templada para alta carga.
 | Cónica "Belleville" | DIN 6796 | Gruesa por diseño para actuar como resorte.
 | De Presión para Allen | DIN 7980 | Más gruesa y compacta que la Grower estándar.

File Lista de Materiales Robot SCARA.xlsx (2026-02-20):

Elemento | Nº de pieza | Miniatura | Estructura de la lista de materiales | CTDAD de unidades | CTDAD | Nº de almacenamiento | Descripción | Rev.
1 | Poste |  | Normal | Cada una | 1
2 | Perfil 2040 200 mm v4 |  | Normal | Cada una | 2
3 | Rueda v |  | Normal | Cada una | 9
4 | DIN 625 SKF - SKF 625-Z |  | Comercial | Cada una | 18 |  | Rodamientos de bolas con acanalado profundo, de una hilera, con escudo Z SKF
5 | ISO 4014 - M5 x 35 |  | Comercial | Cada una | 9 |  | Perno de cabeza hexagonal - Productos de clases A y B
6 | ISO 7093 A - ST 5 - 140 HV |  | Comercial | Cada una | 14 |  | Arandelas planas - Serie grande - Productos de clase A
7 | ISO 4032 - M6 |  | Comercial | Cada una | 3 |  | Tuercas hexagonales, tipo 1 - Productos de clases A y B
8 | Buje paraVslot |  | Normal | Cada una | 8
9 | ISO 4032 - M5 |  | Comercial | Cada una | 12 |  | Tuercas hexagonales, tipo 1 - Productos de clases A y B
10 | ISO 4014 - M8 x 50 |  | Comercial | Cada una | 1 |  | Perno de cabeza hexagonal - Productos de clases A y B
11 | ISO 7089 - 8 |  | Comercial | Cada una | 2 |  | Arandelas planas - Serie normal - Productos de clase A
12 | KS B 2023 - 688 - 8 x 16 x 4 |  | Comercial | Cada una | 2 |  | Rodamientos de bolas, acanalado profundo
13 | Buje 1 para UPN |  | Normal | Cada una | 1
14 | ISO 4032 - M8 |  | Comercial | Cada una | 1 |  | Tuercas hexagonales, tipo 1 - Productos de clases A y B
15 | Engranaje insertado en PIN | *Varía* | Normal | Cada una | 4
16 | Soporte del primer segmento |  | Normal | Cada una | 1
17 | Tapa perfil de aluminio |  | Normal | Cada una | 1
18 | BS 290 SKF - SKF 608-2Z |  | Comercial | Cada una | 2 |  | Rodamientos de bolas con acanalado profundo, de una hilera, con dos escudos Z SKF
19 | ISO 2338 - 8 h8 x 60 |  | Comercial | Cada una | 1 |  | Pasador cilíndrico
20 | ISO 4014 - M6 x 30 |  | Comercial | Cada una | 2 |  | Perno de cabeza hexagonal - Productos de clases A y B
21 | ISO 7089 - 6 |  | Comercial | Cada una | 2 |  | Arandelas planas - Serie normal - Productos de clase A
22 | Tapa de caja reductora - eje z |  | Normal | Cada una | 1
23 | Engranaje GT2 Parametrico | *Varía* | Normal | Cada una | 4
24 | Cono interno - Engranaje 1 eje Z |  | Normal | Cada una | 1
25 | ISO 4032 - M3 |  | Comercial | Cada una | 10 |  | Tuercas hexagonales, tipo 1 - Productos de clases A y B
26 | ISO 4017 - M3 x 16 |  | Comercial | Cada una | 4 |  | Tornillos de cabeza hexagonal
27 | ISO 7089 - 3 |  | Comercial | Cada una | 7 |  | Arandelas planas - Serie normal - Productos de clase A
28 | Caja reductora - eje z |  | Normal | Cada una | 1
29 | Cono interno - Engranaje 2 eje Z |  | Normal | Cada una | 1
30 | DIN 625 SKF - SKF 608-Z |  | Comercial | Cada una | 7 |  | Rodamientos de bolas con acanalado profundo, de una hilera, con escudo Z SKF
31 | ISO 2338 - 8 h8 x 40 |  | Comercial | Cada una | 2 |  | Pasador cilíndrico
32 | Engranaje para nema 17 |  | Normal | Cada una | 3
33 | ISO 4014 - M3 x 20 |  | Comercial | Cada una | 3 |  | Perno de cabeza hexagonal - Productos de clases A y B
34 | Polea Lisa |  | Normal | Cada una | 3
35 | ISO 7045 - M3 x 10 - 4.8 - H |  | Comercial | Cada una | 4 |  | Tornillo de cabeza cilíndrica redondeada con hueco cruciforme tipo H - producto de clase A
36 | ISO 4017 - M5 x 25 |  | Comercial | Cada una | 4 |  | Tornillos de cabeza hexagonal
37 | ISO 7089 - 5 |  | Comercial | Cada una | 4 |  | Arandelas planas - Serie normal - Productos de clase A
38 | JIS B 1521 - 6805 25x37x7 |  | Comercial | Cada una | 3 |  | Rodamiento de bolas, acanalado profundo
39 | ISO 7045 - M3 x 8 - 4.8 - H |  | Comercial | Cada una | 22 |  | Tornillo de cabeza cilíndrica redondeada con hueco cruciforme tipo H - producto de clase A
40 | Segmento inferior |  | Normal | Cada una | 1
41 | Primer segmento - inferior v1.2 |  | Normal | Cada una | 1
42 | ISO 4017 - M4 x 40 |  | Comercial | Cada una | 8 |  | Tornillos de cabeza hexagonal
43 | ISO 4032 - M4 |  | Comercial | Cada una | 20 |  | Tuercas hexagonales, tipo 1 - Productos de clases A y B
44 | Segundo segmento - inferior - Shape generator prueba 2 - 40% |  | Normal | Cada una | 1
45 | ISO 7045 - M4 x 16 - 4.8 - H |  | Comercial | Cada una | 12 |  | Tornillo de cabeza cilíndrica redondeada con hueco cruciforme tipo H - producto de clase A
46 | ISO 7089 - 4 |  | Comercial | Cada una | 12 |  | Arandelas planas - Serie normal - Productos de clase A
47 | Segundo segmento - superior |  | Normal | Cada una | 1
48 | Tercer Segmento - inferior |  | Normal | Cada una | 1
49 | Tercer segmento - superior |  | Normal | Cada una | 1
50 | nema17_pancake |  | Normal | Cada una | 1 |  | Unknown
51 | Joint - Primer segmento | *Varía* | Normal | Cada una | 2
52 | ISO 2338 - 8 h8 x 50 |  | Comercial | Cada una | 2 |  | Pasador cilíndrico
53 | ISO 2338 - 8 h8 x 30 |  | Comercial | Cada una | 1 |  | Pasador cilíndrico
54 | Servo SG90 |  | Normal | Cada una | 1
55 | Logitech c270 |  | Normal | Cada una | 1
56 | Base - version 2 |  | Normal | Cada una | 1
57 | Round_gear |  | Normal | Cada una | 1
58 | Tapa - Gripper |  | Normal | Cada una | 1
59 | Pata derecha | *Varía* | Normal | Cada una | 2
60 | Base Marcador ECU |  | Normal | Cada una | 1

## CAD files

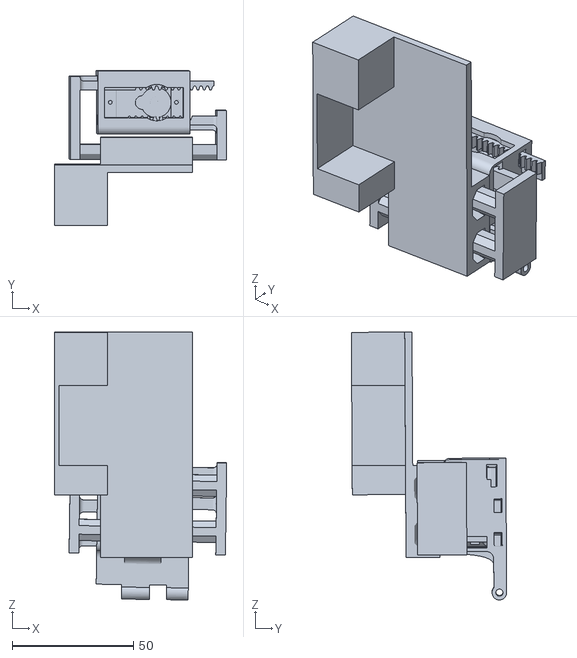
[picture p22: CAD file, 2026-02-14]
Piezas/Robot SCARA/Ensamblajes/Ensamblaje - Gripper.stl
71.1 x 64.0 x 110.5

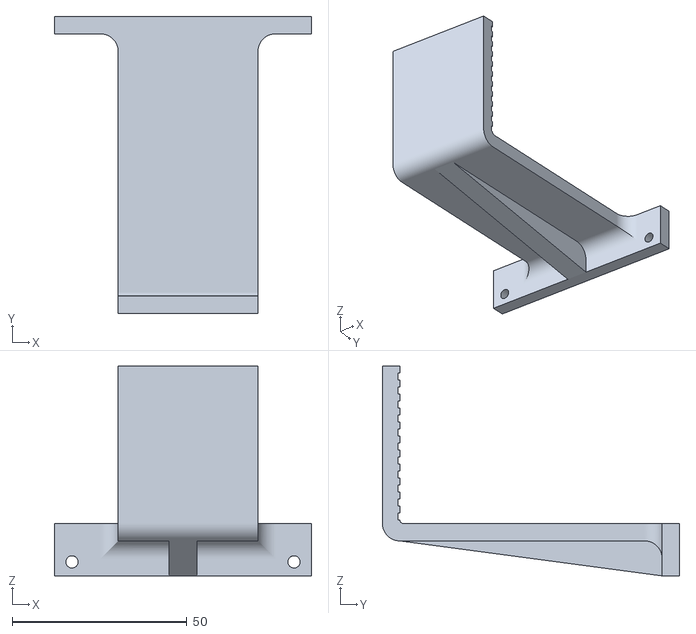
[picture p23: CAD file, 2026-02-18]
Piezas/Lavadora de ECUs/Garra inferior.stl
73.5 x 85.0 x 60.0

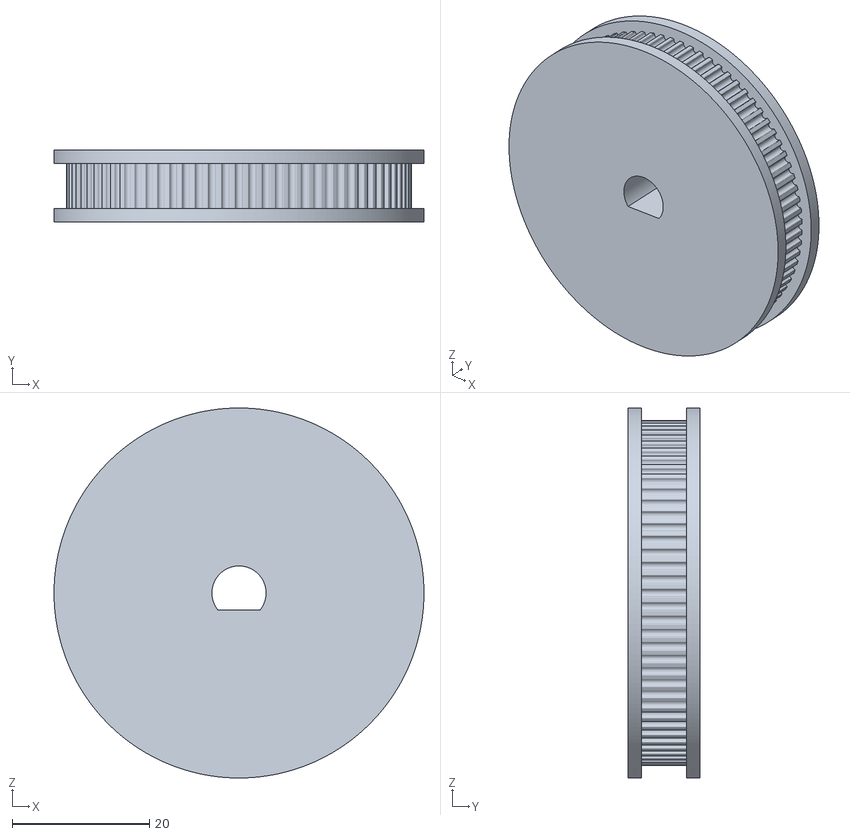
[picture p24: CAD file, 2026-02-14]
Piezas/Robot SCARA/Eje Z/Engranaje 1 - Reductor Eje Z - version chabeta.stl
54.0 x 10.5 x 54.0

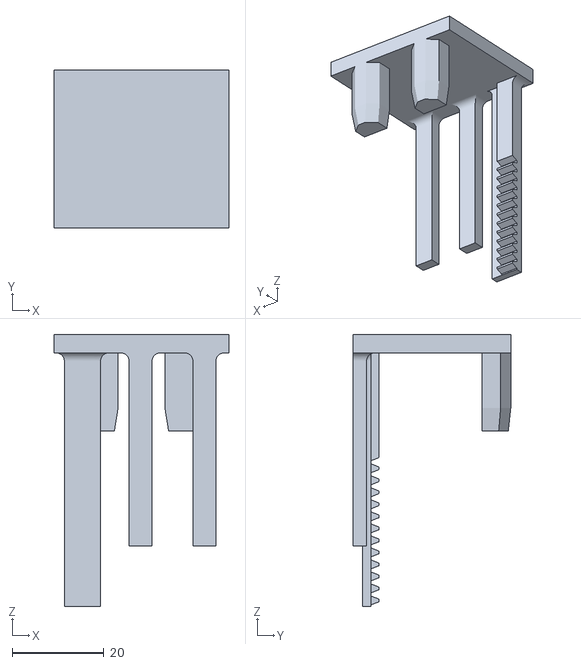
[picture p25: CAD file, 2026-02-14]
Piezas/Robot SCARA/Gripper/Pata Izquierda - versión 4.stl
38.0 x 34.3 x 59.2

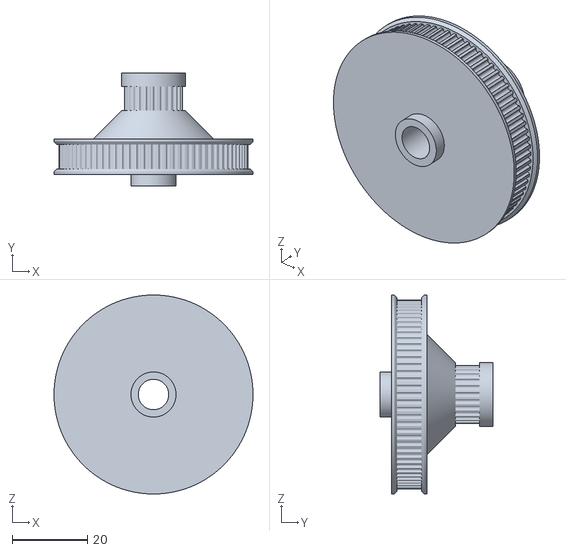
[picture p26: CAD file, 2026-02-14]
Piezas/Robot SCARA/Primer Segmento/Engrajane doble - primer segmento.stl
53.0 x 30.0 x 53.0

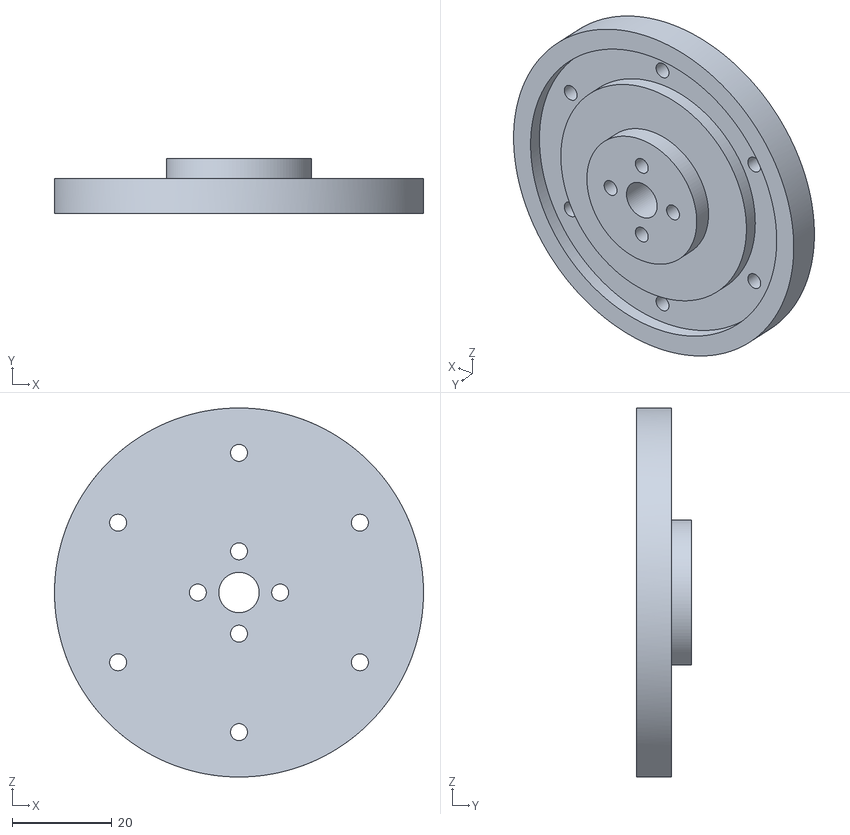
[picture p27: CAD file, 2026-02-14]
Piezas/Robot SCARA/Segundo Segmento/Joint - Segundo segmento.stl
74.0 x 11.0 x 74.0

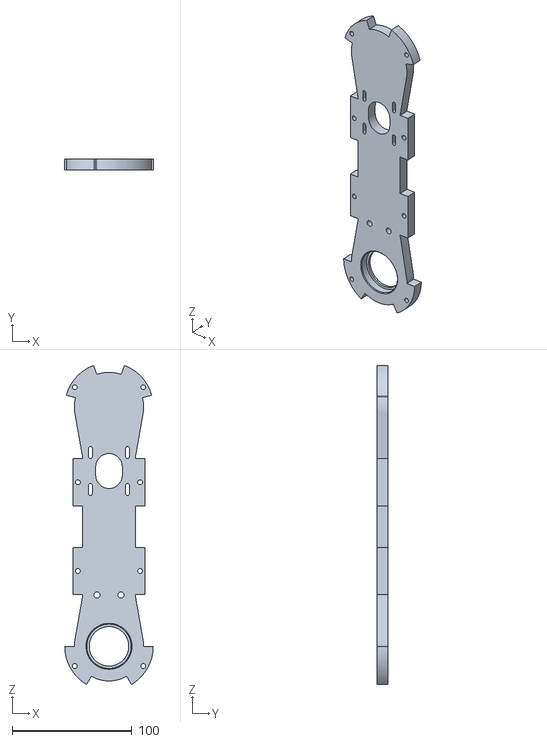
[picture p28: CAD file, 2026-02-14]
Piezas/Robot SCARA/Tercer Segmento/Tercer Segmento - inferior.stl
74.0 x 9.00 x 266.6

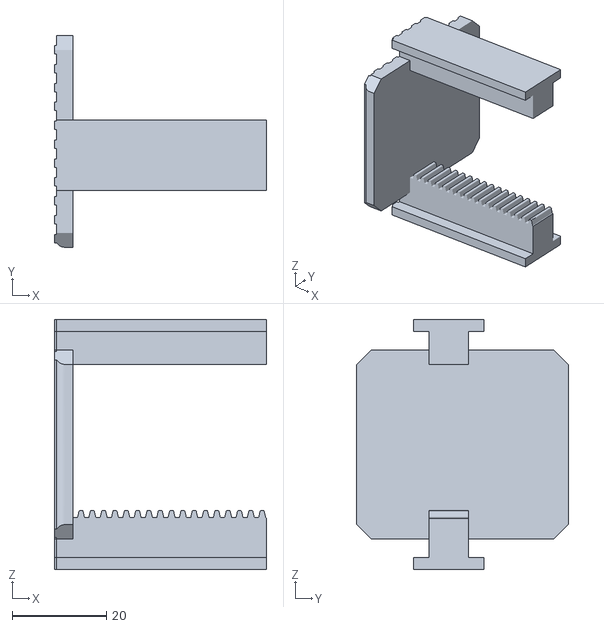
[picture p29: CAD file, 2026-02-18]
Piezas/Lavadora de ECUs/Garra superior.stl
45.0 x 44.9 x 53.0

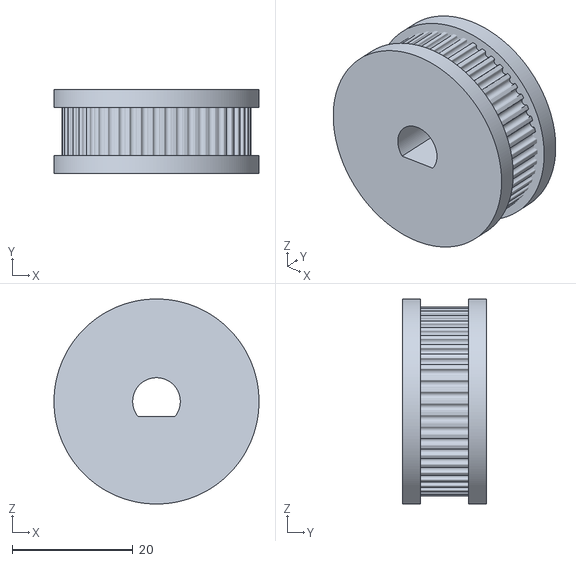
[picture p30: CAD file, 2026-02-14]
Piezas/Robot SCARA/Eje Z/Engranaje 2 reductor Eje Z - version chabeta.stl
34.0 x 14.0 x 34.0

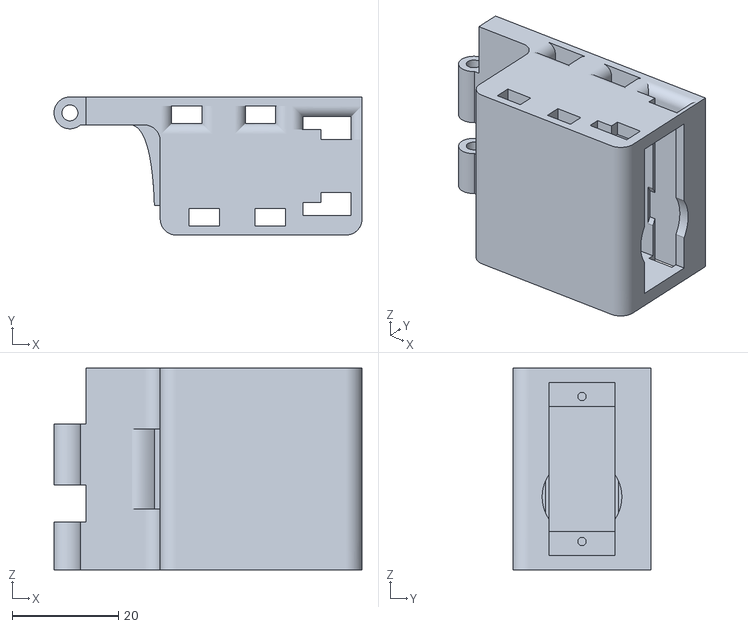
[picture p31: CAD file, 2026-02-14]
Piezas/Robot SCARA/Gripper/Base - version 3.stl
58.0 x 26.0 x 38.0

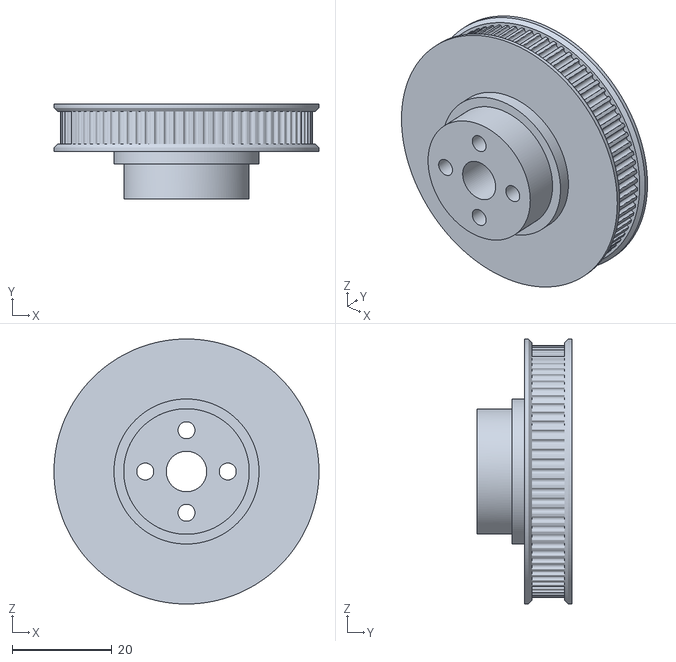
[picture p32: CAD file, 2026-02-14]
Piezas/Robot SCARA/Primer Segmento/Engranaje simple - primer segmento.stl
53.0 x 19.0 x 53.0

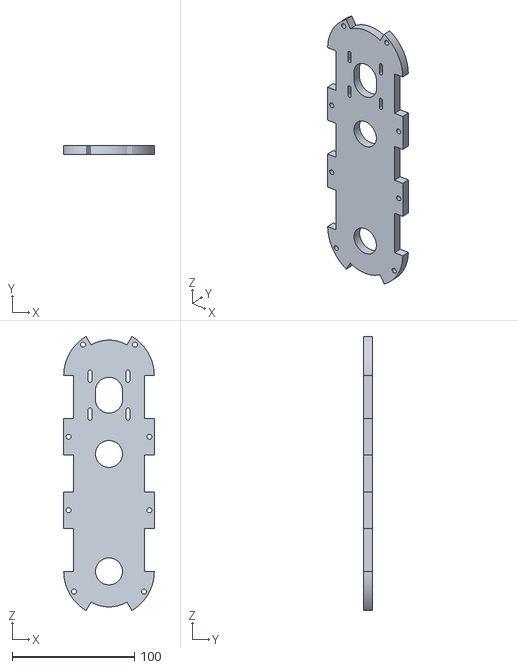
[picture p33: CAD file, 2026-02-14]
Piezas/Robot SCARA/Segundo Segmento/Segundo segmento - superior.stl
74.0 x 7.00 x 223.9

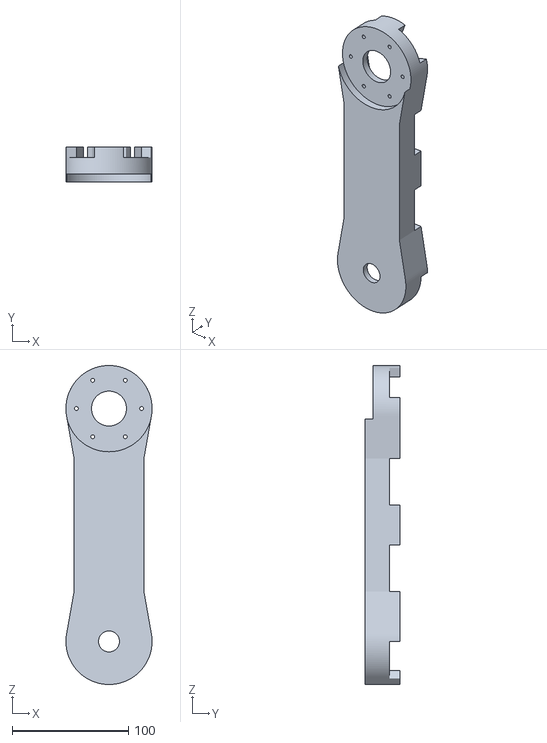
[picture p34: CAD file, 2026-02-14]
Piezas/Robot SCARA/Tercer Segmento/Tercer segmento - superior.stl
74.0 x 30.0 x 274.0

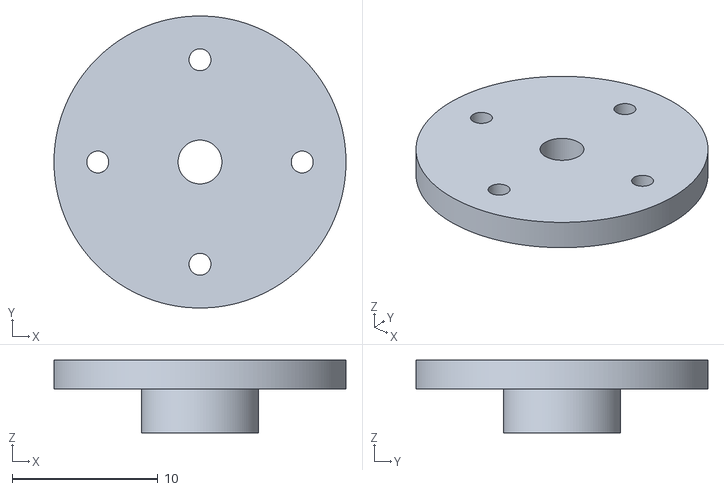
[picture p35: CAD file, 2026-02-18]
Piezas/Lavadora de ECUs/Brida de servo.stl
20.0 x 20.0 x 5.00

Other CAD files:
Piezas/Robot SCARA/Eje Z/Tapa - Caja para Electrónica.stl
Piezas/Robot SCARA/Gripper/Base Marcador ECU + Gripper.stl
Piezas/Robot SCARA/Primer Segmento/Primer segmento - superior v1.2.stl
Piezas/Robot SCARA/Segundo Segmento/Segundo segmento - inferior - Shape generator prueba 2 - 40%.stl
Piezas/Lavadora de ECUs/Base.ipt
Piezas/Lavadora de ECUs/Base.stl
Piezas/Lavadora de ECUs/Brida de servo.ipt
Piezas/Lavadora de ECUs/Case servo MG.ipt
Piezas/Lavadora de ECUs/Case servo MG.stl
Piezas/Lavadora de ECUs/Garra inferior.ipt
Piezas/Lavadora de ECUs/Guía lateral.ipt
Piezas/Lavadora de ECUs/Guía.ipt
Piezas/Lavadora de ECUs/Guía.stl
Piezas/Lavadora de ECUs/Mesa.ipt
Piezas/Lavadora de ECUs/Mesa.stl
Piezas/Lavadora de ECUs/Sujeción de servo a mesa s-c.ipt
Piezas/Lavadora de ECUs/Sujeción de servo a mesa s-c.stl
Piezas/Lavadora de ECUs/Sujeción de servo a mesa.ipt
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

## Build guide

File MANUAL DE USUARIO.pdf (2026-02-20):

## MANUAL DE USUARIO

Proyecto SCARA + Lavadora de ECUs Versión: 1.0
Fecha: 20/02/2026
Autor:

## 1. Introducción rápida

Este documento describe el uso, los procedimientos de operación, las precauciones de seguridad y las tareas de mantenimiento del sistema SCARA + Lavadora de ECUs. El sistema automatiza la detección, manipulación y lavado de unidades de control electrónico (ECU) mediante un robot SCARA, un módulo lavadorA y un sistema de visión.

El manual está pensado para personal de laboratorio y taller sin necesidad de profundos conocimientos de ingeniería, y debe consultarse antes de operar el equipo.

## 2. Componentes principales

- Robot SCARA con efector (gripper) impreso en PETG, capacidad de agarre para la pieza adaptadora 3D.
- Cámara de visión montada en el efector (Logitech C270 HD 720p o equivalente). Detecta QRs y calcula la pose.
- Lavadora (caja): estructura con paredes acrílicas, inyectores fijos en techo, grippers internos accionados por servos, guías lineales verticales accionadas por NEMA17, y batea en el piso (zona de inmersión).
- Bomba de inyectores (presión operativa 2.7–4.1 bar)
- Controladores electrónicos: SCARA (Arduino Mega + RAMPS 1.4; Lavadora) Arduino Mega + RAMPS 1.4; comunicación de eventos por ESP32.
- Fuentes: SCARA 12 V 15 A; Lavadora 12 V 20 A y 5 V 20 A.
- Pieza adaptadora 3D (pata 3D) con QR y ranuras autocentrantes (se inserta a presión en la ECU para estandarizar su sujeción)

## 3. Requisitos previos y condiciones de seguridad

Antes de operar:

- Leer este manual completamente.
- Uso sólo en entorno controlado (taller/laboratorio) con ventilación adecuada.
- Verificar que todas las conexiones eléctricas estén en buen estado y las fuentes correctas.
- Confirmar que la mesa de trabajo está libre de objetos extraños y que la lavadora tiene suficiente líquido en la batea.

Precauciones importantes:

- Mantener manos y ropa alejadas de las partes móviles durante la operación.
- Uso de equipo de protección personal (guantes, gafas) al manipular piezas con residuos o solventes.
- En caso de derrame o fuga, cortar alimentación y evacuar el área si hay riesgo de incendio.

## 4. Preparación del equipo

1. Inspeccionar visualmente el robot, la lavadora y el cableado.
2. Confirmar que las fuentes están correctamente conectadas (12 V y 5 V según subsistema).
3. Revisar que la batea tenga líquido suficiente (si se va a usar inmersión).
4. Verificar que la pieza adaptadora 3D esté correctamente montada en cada ECU que se procese.
5. Encender PC / software de visión y comprobar que la cámara responde.
6. Encender controladores SCARA y Lavadora; comprobar que los finales de carrera y servos responden en homing.
7. Asegurarse de que no haya personas en la zona de alcance del robot.
8. Confirmar que el ESP32 está operativo y conectado entre SCARA y la lavadora.

## 5. Procedimiento operativo — ciclo estándar

Nota: seguir el flujo en este orden. Si algo falla, detener y consultar sección “Solución de problemas”.

### 5.1 Carga de piezas

1. Colocar las ECUs en la mesa de trabajo dentro del alcance del SCARA. Asegurarse de que cada ECU tenga la pieza adaptadora 3D insertada y el QR visible.
2. Abrir el software en la PC y seleccionar “Iniciar rutina” / “Play”.

### 5.2 Escaneo y detección

3. El robot realizará una rutina de escaneo por varias zonas predeterminadas. La cámara tomará imágenes en cada punto.
4. Si la cámara detecta un QR, la PC envía la posición de captura al controlador del SCARA.

### 5.3 Pick & Transfer

5. El SCARA mueve el efector a la posición de captura y cierra el gripper para sujetar la pieza. La geometría autocentrante de la pata 3D alinea la placa.
6. El SCARA traslada la ECU a la zona de transferencia frente a la lavadora y posiciona la pieza para entrega.

### 5.4 Cedencia y lavado

7. El SCARA envía la señal (Mediante un ESP32) a la lavadora indicando “pieza colocada”. La lavadora acciona sus servos y cierra sus grippers internos.
8. El SCARA se retira. La lavadora ejecuta el ciclo preconfigurado:
- Aspersión cara A (ej.: 15 s).
- Rotación hasta exponer cara B.
- Aspersión cara B (ej.: 15 s).
- Retorno a posición y descenso para inmersión en batea (ej.: 20 s).
9. Al finalizar, la lavadora notifica “ciclo finalizado” al SCARA.

### 5.5 Recuperación y salida

10. El SCARA regresa, toma la ECU, y la deposita en la posición de salida designada.
11. Repetir el ciclo para la siguiente ECU o detener la rutina si no se detectan más piezas.

## 6. Parámetros configurables

- Tiempo de aspersión por cara: 15 s (configurable).
- Tiempo de inmersión en batea: 20 s (configurable).
- Distancias y puntos de escaneo (definidos en software).
- Perfiles de movimiento del robot (velocidad/ aceleración) — ajustar con cuidado para evitar pérdidas de paso.

## 7. Mantenimiento y verificaciones periódicas

Diario (antes de cada jornada):

- Inspeccionar visualmente cables, poleas y correas.
- Comprobar que los finales de carrera funcionan.
- Verificar nivel de líquido en la batea (si aplica).

Semanal:

- Limpiar boquillas e inyectores (si hay obstrucción).
- Revisar apriete de insertos y tornillos visibles.
- Comprobar estado de los servos y conexiones I²C (AS5600, TCA9548A).

Mensual:

- Revisar desgaste de correas GT2 y tensado.
- Inspeccionar rodamientos por ruidos o juego.
- Revisar estado de los drivers DRV8825 (temperatura, disipadores).

Siempre después de ensayos intensivos o golpes:

- Revisar alineación de gripper y pieza adaptadora.
- Comprobar encoders y ajustar homing si hace falta.

## 8. Repuestos recomendados

- Drivers Pololu / DRV8825 — 1–2 unidades de repuesto.
- Motores NEMA17 — 1 unidad (si el stock lo permite).
- Rodamientos 625 y 6805 — según configuración, 1–2 de cada tipo.
- Servos MG90 — 2 unidades.
- Correas GT2 6 mm (spare).
- Tornillería M3 con insertos roscados (spare).

## 9. Solución de problemas — troubleshooting

Esta sección reúne procedimientos prácticos, listas de verificación y flujos de diagnóstico para resolver fallas comunes del sistema SCARA + Lavadora de ECUs. Está pensada para un operario o técnico de laboratorio: combina medidas rápidas para recuperar funcionamiento (workarounds) y tests más profundos para identificar la raíz del problema. Antes de cualquier intervención eléctrica o mecánica, leer y respetar las normas de seguridad del laboratorio.

## Prioridad y seguridad

1. Parada segura: si hay riesgo (fuga, chispas, piezas sueltas) detener la operación con el paro por software. Si la situación es peligrosa y hay E-Stop físico disponible, accionarlo.
2. Desenergizar: para trabajos que impliquen abrir la carcasa o tocar la electrónica, cortar la alimentación principal (12 V y 5 V).
3. EPP: usar guantes, gafas y protección frente a líquidos/solventes.
4. Área despejada: mantener la zona libre de personas no autorizadas.
5. Registro: anotar fecha/hora, quién interviene y síntoma observado antes de modificar parámetros — esto facilita volver atrás si hay efectos imprevistos.

## Flujo general de diagnóstico

1. Identificar el síntoma claro (p. ej. “no detecta QR”, “motor no gira”, “fuga de líquido”).
2. Clasificar a subsistema: Visión / SCARA (mecánico) / Lavadora (mecánico) / Bombeo / Electrónica / Comunicaciones.
3. Inspección visual rápida (5 minutos): cables sueltos, conectores, correas, rodamientos con juego, fugas.
4. Pruebas de energía y sensores (multímetro): verificar tensiones de fuente, presencia 12 V/5 V, continuidad fusibles.
5. Prueba funcional mínima: ejecutar el “paso de humo” — encender y ejecutar la rutina más simple (p. ej. homing o mover 10 mm). Observar errores en logs/LEDs.
6. Recolección de datos: anotar mensajes de error en software, capturas de pantalla, valores de corriente, temperaturas.
7. Acción correctiva: aplicar la solución con la prioridad menor invasiva → mayor invasiva.
8. Verificación: ejecutar ciclo de prueba (1–5 ciclos) y monitorizar.

## Tabla rápida: Síntoma → causas probables → acción inmediata

Síntoma | Causas probables | Comprobación rápida | Acción inmediata
Cámara no aparece en PC / consola | Cable USB suelto; dispositivo no reconocido; driver | Conectar la cámara a otra PC; comprobar en administrador de dispositivos | Reemplazar cable; reinstalar driver; usar cámara alternativa
Cámara detecta mal los QRs | Iluminación / QR sucio / enfoque | Fotografiar QR con teléfono; inspeccionar iluminación; comprobar nitidez | Limpiar QR; ajustar iluminación; bajar velocidad robot durante escaneo
Robot no alcanza posición de pick | Paso perdido; encoder fallo; tope mecánico | Mover manualmente en modo jog, escuchar pasos | Revisar conexiones de motor, tensionar correas, hacer homing lento
Pérdida de pasos frecuentes | Aceleración/profiles muy agresivos; motor sobrecorriente | Observar corriente de motor (clamp) y temperatura driver | Reducir aceleración/velocidad, aumentar microstepping, mejorar disipación
Motor no gira | Driver desconectado; Vmot ausente; cable motor roto | Medir 12 V en VMOT, comprobar LEDs en driver | Reemplazar driver temporalmente; probar motor en otro eje
Endstop no se detecta | Cable suelto; señal invertida | Comprobar continuidad cable; leer estado digital en MCU | Reconectar, invertir señal en firmware si necesario
Lavadora no inicia ciclo | No recibe señal ESP32; bomba sin alimentación | Medir 12 V en entrada bomba; chequear pin de señal | Verificar ESP32 (LEDs), reemplazar relevo o fuse, comprobar driver bomba
Bomba no genera presión | Obstrucción; bomba defectuosa; alimentación | Escuchar funcionamiento de bomba; medir corriente | Limpiar línea, purgar; si no gira, reemplazar bomba
Fuga de líquido | Junta dañada; tara de batea | Inspección visual | Drenar, limpiar, reparar junta, secar y volver a sellar

Síntoma | Causas probables | Comprobación rápida | Acción inmediata
Servo no responde | Alimentación 5 V caída; cable señal dañado | Medir 5 V, probar servo con fuente separada | Reemplazar servo; revisar alimentación 5 V
I²C no responde (AS5600/TCA9548A) | Pull-ups ausentes; bus colapsado | Escanear dirección I²C (i2cdetect) o leer por software | Revisar cableado, desconectar dispositivos hasta encontrar fallo

## Diagnósticos detallados por subsistema

A) Visión (cámara + detección QR / modelo YOLO)

Síntomas frecuentes: no detecta QR, detección errática, baja tasa de frames, latencia alta.

Checks rápidos

- Verificar alimentación USB y estado en la PC (Device Manager / lsusb / v4l2-

ctl --list-devices).
- Abrir software de captura y comprobar FPS y exposición.
- Inspeccionar lente y QR: limpieza, rotura, reflejos por acrílico.
- Probar QR impreso con teléfono: si el teléfono lo lee y la cámara no, fallo de imagen/iluminación.

Pruebas funcionales

1. Ejecutar script de prueba de cámara (captura imagen, guardar).
2. Forzar diferentes exposiciones/ganancias y ver si mejora la detección.
3. Desplegar imagen en PC y comprobar distorsión; si está excesiva, recalibrar intrínsecos.

Acciones

- Ajustar iluminación: agregar difusores o fuentes LED.
- Reposicionar la cámara o bajar velocidad de movimiento durante captura.
- Reentrenar o ajustar umbral del detector si falsos positivos/negativos.
- Si la cámara está dañada, sustituir por una webcam equivalente (C270 funciona como referencia).

Datos a recolectar (para bug report):

- Captura cruda (imagen .png), configuración de cámara (resolución, FPS, exposure), logs del detector (probabilidades), timestamp.

B) Movimiento / SCARA (motores paso a paso, drivers, correas)

Síntomas frecuentes: pérdida de pasos, ruidos, vibración, inexactitud repetible.

Checks rápidos

- Estado visual: correas tensas, poleas montadas, tornillos de fijación.
- Temperatura drivers y motores (tacto o termómetro IR).
- Conexiones de motor (A+/A-/B+/B-), comprobar continuidad.

Pruebas

1. Homing lento: ejecutar homing a baja velocidad para detectar fricción o bloqueos.
2. Movimiento de prueba: jog en ejes pequeños (10–20 mm) y observar respuesta.
3. Medir corriente de fase con pinza o sensor (picos y rms).
4. Probar mover motor desconectado del eje — si gira sin carga, el problema es mecánico.

Acciones

- Reducir aceleraciones/velocidades en firmware si pérdida de pasos.
- Ajustar corriente del driver (con potenciómetro) sin exceder temp ratings; revisar disipadores y ventilación.
- Rehacer tensado o sustituir correas con desgaste.
- Comprobar ejes y rodamientos por juego; si hay juego en rodamientos, plan de substitución (ej. 625/6805).

Medidas / umbrales orientativos

- Temperatura driver: si >70°C en operación continua, implementar ventilación o reducir corriente.
- Corriente por fase: comparar con la corriente de trabajo configurada (p. ej. ~1.7 A/fase) y con la capacidad del driver.
C) Gripper y mecanismo de intercambio con lavadora

Síntomas: no sujeta, resbala, no libera, piezas mal alineadas.

Checks

- Comprobar geometría de la pieza 3D y presencia de residuos que impidan el encastre.
- Verificar actuador del gripper (servo o motor) opera al recibir señal.
- Revisar sensores (si existen) o confirmar confirmación por software.

Pruebas

1. Test manual: con robot en modo manual, hacer cierre/abrir gripper y comprobar fuerza y recorrido.
2. Simular entrega: posicionar la pieza y pedir a la lavadora que cierre sus pinzas (sin iniciar ciclo) para verificar sujeción.

Acciones

- Ajustar posición de entrega (offsets) si la alineación es consistentemente sesgada.
- Reemplazar servo si muestra comportamiento errático (jitter, sin fuerza).
- Limpiar ranuras y piezas adaptadoras para asegurar ajuste.
D) Lavadora (bomba, inyectores, servos, guías)

Síntomas: bomba no entrega presión; inyectores bloqueados; servos no giran; gripper interno no baja.

Checks

- Estado físico de líneas: mangueras, boquillas, depósitos.
- Tensión en bornes de bomba (12 V) y consumo de corriente (normal / pico).
- Finales de carrera en guías verticales (Z) y lectura en MCU.

Pruebas

1. Prueba directa de bomba: alimentar bomba desde fuente controlada y observar presión/caudal (si es seguro).
2. Limpiar nozzles con aguja o aire comprimido (si es compatible).
3. Ejecutar ciclo de servos en vacío (comando manual) y verificar movimiento.

Acciones

- Purga de línea si hay aire; verificar filtros.
- Reemplazo de boquilla si corroída o dañada.
- Si bomba falla en carga, medir corriente y considerar reemplazo.

E) Electrónica y alimentación (fuentes, 5 V / 12 V, drivers)

Síntomas: reinicios, perdida de comunicación, voltajes fuera de rango.

Checks

- Medir con multímetro: 12.0 ±0.5 V en VMOT, 5.0 ±0.2 V en Vlogic.
- Revisar LEDs de presencia de tensión y fusibles.
- Comprobar que el ground de todos los subsistemas esté común (evitar lazos de masa).

Pruebas

1. Verificar que al conectar cargas (motores) las tensiones no caigan por debajo de límites.
2. Medir ripple o ruidos en salida con osciloscopio si hay reinicios.
3. Test de arranque secuencial: encender 5 V lógica primero luego 12 V potencia (si el diseño lo recomienda).

Acciones

- Sustituir fusible si quemado; investigar causa (corto).
- Añadir condensadores de desacoplo o mejorar masa común si hay ruido.
- Si fuente no da corriente nominal, reemplazar por una fuente con más capacidad.
F) Comunicaciones (PC ↔ ESP32 ↔ Arduinos)

Síntomas: lavadora no recibe señales; PC no envía comandos; timeouts.

Checks

- Confirmar LEDs de enlace en ESP32; ping serial si aplica.
- Comprobar cables USB/TTL; probar con cable y puerto distintos.
- Revisar logs en PC (console output) para errores.

Pruebas

1. Enviar comando simple desde PC y esperar ACK; si no responde, hacer loopback básico (software).
2. Leer salida serial del Arduino para ver mensajes de estado.
3. Reiniciar ESP32 y observar logs de arranque.

Acciones

- Reconfigurar baudrate si comunicación corrupta.
- Reemplazar cable defectuoso.
- Subir nuevamente firmware si corrupción de memoria.

## Procedimiento de diagnóstico avanzado (ejemplo: “Motor J1 falla al mover”)

1. Inspección física (5 min): cables, poleas, correas, rodamientos.
2. Comprobación eléctrica: medir 12 V en VMOT del driver; medir Vcc lógica.
3. Probar driver swap: intercambiar driver DRV8825 con otro eje que funcione; si el problema se traslada con el driver, driver defectuoso.
4. Probar motor directo: desconectar del acoplamiento y hacer girar motor con el driver en modo jog; si motor no gira, probar motor en otro canal.
5. Medir corriente del motor: con pinza o sensor, comparar con corriente configurada; verificar posibilidad de limitación por driver o PSU.
6. Comprobar firmware: enviar movimiento pequeño por serial y observar error/ACK.
7. Si mecánica: con motor desconectado y eje libre, mover manualmente y verificar rodamientos; si se siente rugosidad, sustituir rodamientos 625/6805 según ubicación.
8. Registrar: anotar hallazgos y revertir cambios temporales.

## Recomendaciones finales y límites del manual

- No modificar microajustes críticos (limitadores de corriente de drivers) sin formación y sin registrar el valor previo.
- Si hay dudas en la electrónica de potencia, contactar a la persona responsable antes de intentar reparaciones.
- Mantener inventario de repuestos crítico para reducir downtime (drivers, correas, rodamientos, servos).
- Tras cualquier reparación mayor, ejecutar el plan de ensayo (ver §4 del Manual) y validar 10 ciclos antes de volver a operación normal.

## 10. Consideraciones finales y advertencias

- Este manual describe la operación del prototipo actual. Cualquier modificación de hardware o software debe ser documentada y es responsabilidad del equipo técnico evaluar su impacto en seguridad.
- El prototipo fue probado con agua. Si se decide emplear alcohol u otros solventes, no usar el sistema sin las adecuaciones de seguridad e instalaciones apropiadas (cerramiento, ventilación, certificaciones).
- Dado que el prototipo no tiene E-Stop físico, se recomienda extremar precauciones y considerar la implementación de un E-Stop antes de operación fuera de entornos de pruebas controladas.

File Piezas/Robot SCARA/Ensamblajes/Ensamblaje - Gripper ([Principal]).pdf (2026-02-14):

setPageBoxes("Crop", 0, 0, [0,2000,2000,0]);

TÍTULO N.º DE PIEZA | Ensamblaje - Gripper REVISIÓN DISEÑADOR | bello INGENIERO NOTAS

LA INFORMACIÓN O LOS MATERIALES DE ESTE DOCUMENTO SON PROPIEDAD E INFORMACIÓN RESTRINGIDA O MATERIALES DEL AUTOR. ESTA INFORMACIÓN NO SE PUEDE UTILIZAR, REPRODUCIR, PUBLICAR O REVELAR A TERCEROS SIN AUTORIZACIÓN POR ESCRITO. DEBE UTILIZARSE SOLO PARA LA FABRICACIÓN DE LOS ELEMENTOS ESPECIFICADOS EN EL DOCUMENTO.

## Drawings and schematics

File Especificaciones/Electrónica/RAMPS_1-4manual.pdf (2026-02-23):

# RAMPS 1.4 http://reprap.org/wiki/ramps

This is open hardware: you can redistribute it and/or modify it under the terms of the GNU General Public License as published by the Free Software Foundation, either version 3 of the License, or (at your option) any later version.

This hardware design is distributed in the hope that it will be useful, but WITHOUT ANY WARRANTY; without even the implied warranty of MERCHANTABILITY or FITNESS FOR A PARTICULAR PURPOSE. See the GNU General Public License for more details.

You should have received a copy of the GNU General Public License along with this program. If not, see <http://www.gnu.org/licenses/>.

!!! Reversing input power, and/or inserting stepper drivers incorrectly will destroy electronics and cause fire hazard!!!

Test all electronics thoroughly before placing into service.

Do not leave power supplied to electronics unattended, or run machines unattended due to the risk of fire and malfunction.

This is NOT a toy and it contains
small and sharp parts. Children can
choke or suffocate by swallowing small objects. Keep all parts away from children and never leave printer/parts unattended.

Bill of Materials
Qty Part Name | Value | Package
3 C1,C5,C8 | 10uF | 153CLV-0405
1 C2 | 100nF | C0805
6 C3,C4,C6,C7,C9,C10 | 100uF | 153CLV-0605
2 D1,D2 | 1N4004 | DO41-10
1 F1 | MFR500 | MFR500
1 F2 | MFR1100 | MFR1100
1 LED1 | green | CHIP-LED0805
3 LED2,LED3,LED4 | red | CHIP-LED0805
3 Q1,Q2,Q3 | STP55NF06L TO220BV
5 R1,R7,R11,R21,R22 | 4.7K (1%) | R0805
8 R2,R3,R4,R5,R6,R8,R9,R10100k | R0805
1 R12 | 1K | R0805
3 R23,R24,R26 | 1.8K | R0806
3 R13,R14,R15 | 10r | R0805
5 R16,R17,R18,R19,R20 | 10k | R0805
1 S1 | B3F-3100 | B3F-31XX
1 U$2 | 282837-6 | 282837-6
1 X4 | MSTBA4 | MSTBA4
1 | 0.1” 18x2 pin
8 | 0.1” 2x3 pin
5 | 0.1” 8x1 pin
2 | 0.1” 6x1 pin
6 | 0.1” 4x1 pin
2 | 0.1” 24x1 female
4 | 0.1” 8x1 female
15 | 0.1” 2 pin jumper

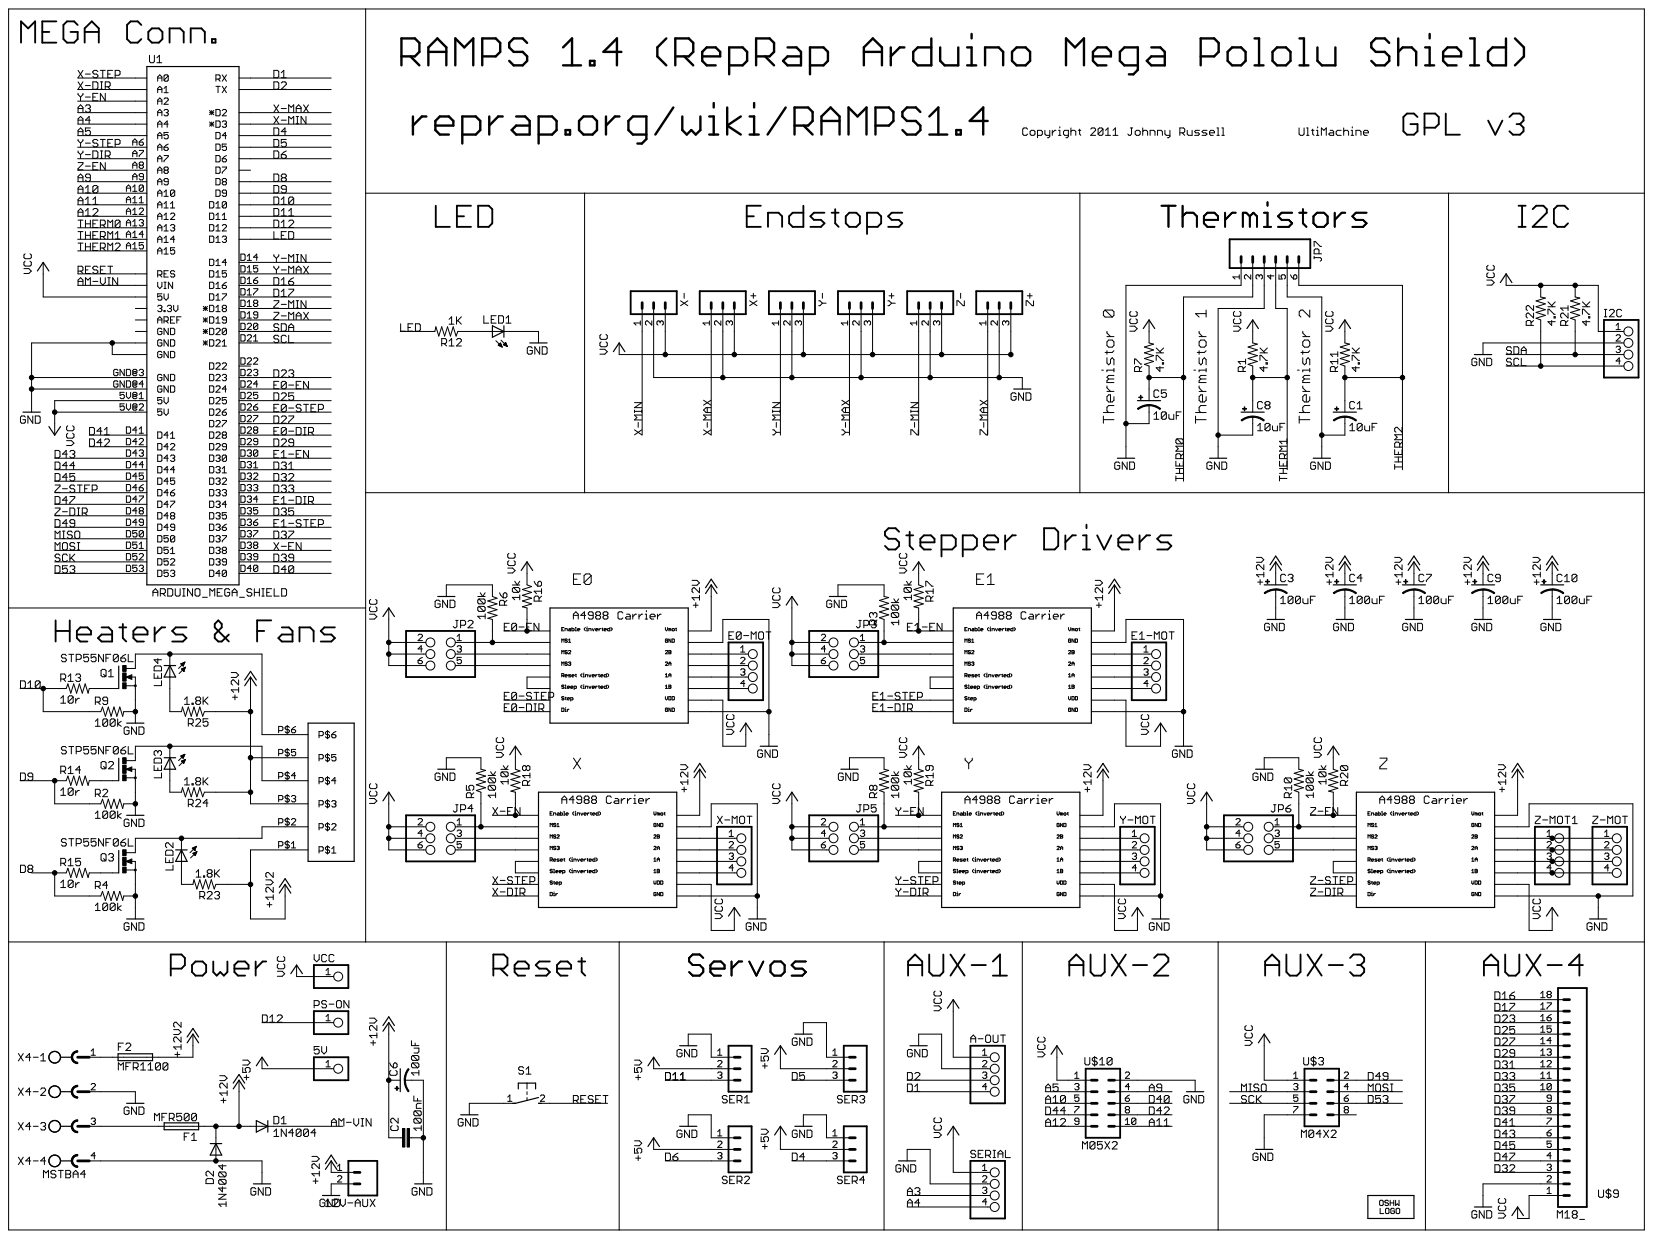
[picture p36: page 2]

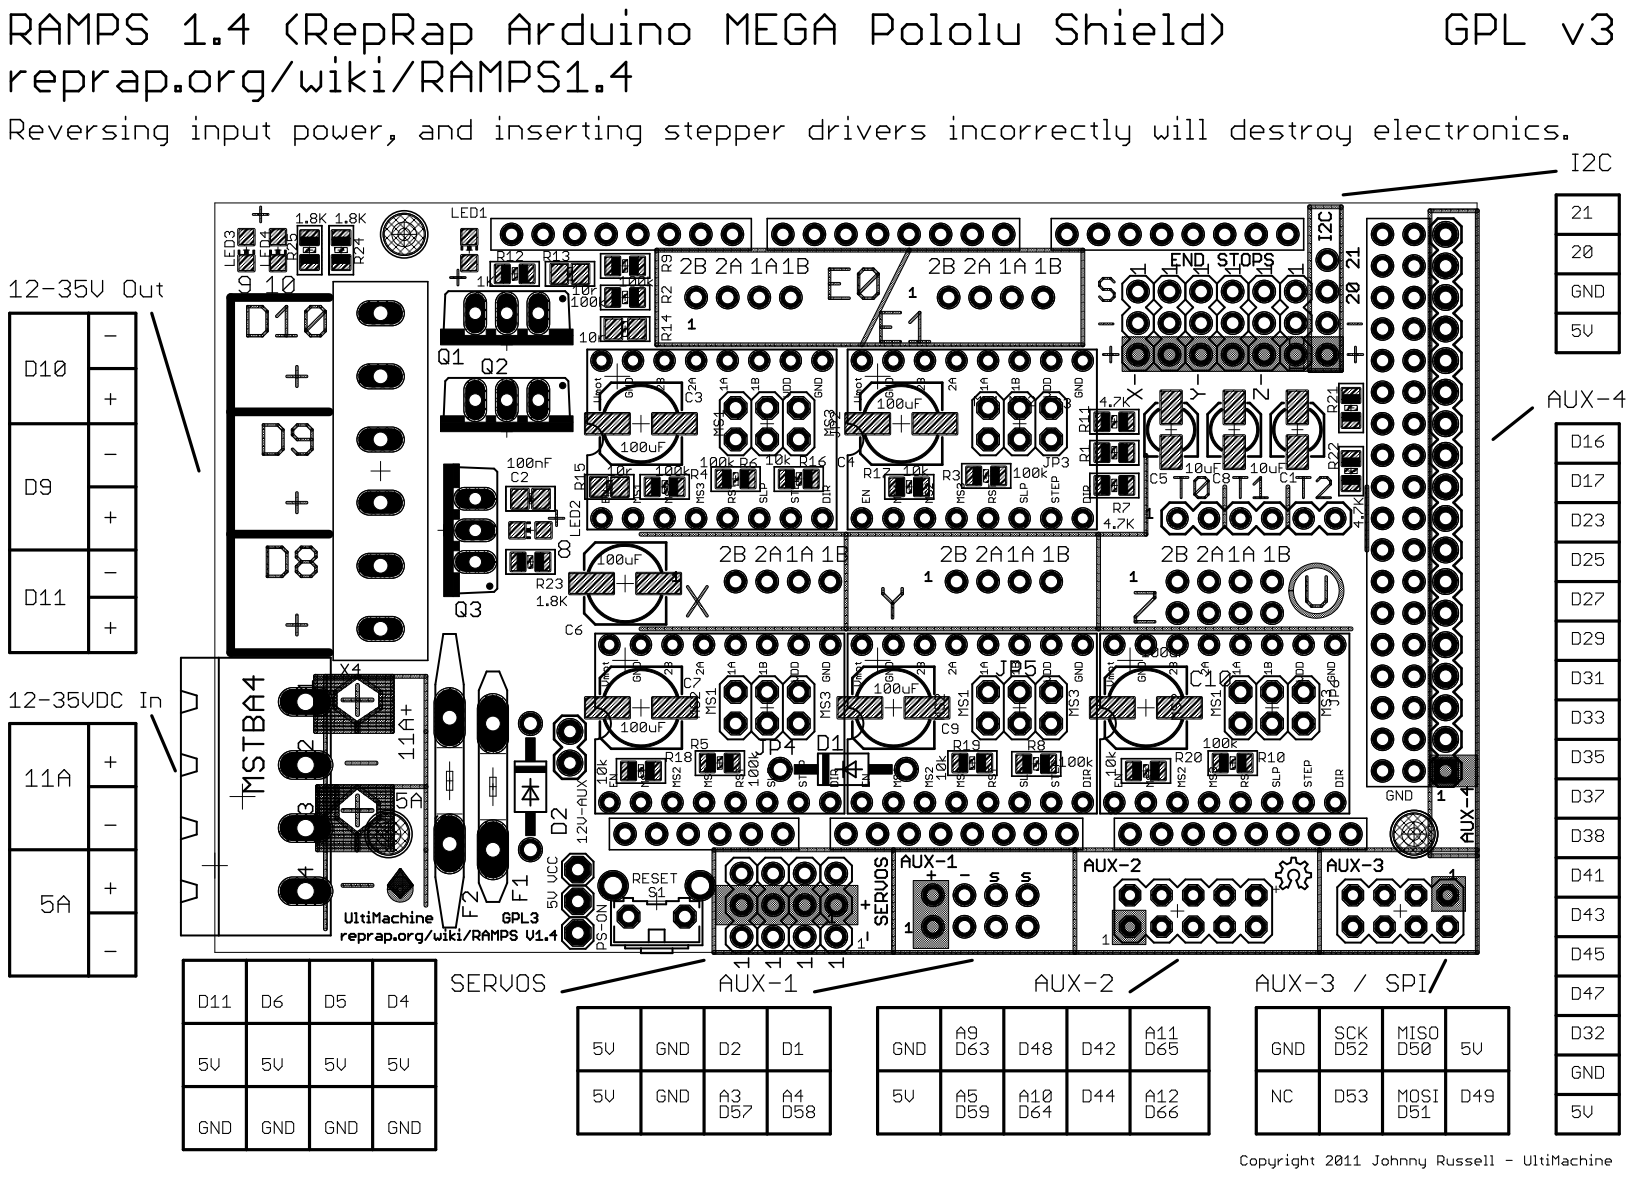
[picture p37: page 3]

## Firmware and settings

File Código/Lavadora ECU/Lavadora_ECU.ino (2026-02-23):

#include <Servo.h> // Librería para controlar servos con Arduino

// ================== Pines RAMPS 1.4 ==================
// Motor A (Lavadora)
#define ENA 66
#define IN1 63
#define IN2 65

// Motor B (Inyector)
#define ENB 64
#define IN3 44
#define IN4 59

// Motores NEMA eje X e Y
#define X_STEP_PIN 54
#define X_DIR_PIN 55
#define X_ENABLE_PIN 38

#define Y_STEP_PIN 60
#define Y_DIR_PIN 61
#define Y_ENABLE_PIN 56

// Endstops
#define Y_MIN_PIN 14
#define Y_MAX_PIN 15

// Servos
#define SERVO1_PIN 11
#define SERVO2_PIN 6
#define SERVO3_PIN 5
#define SERVO4_PIN 4

// ================== Variables ==================
const float LEADSCREW_PITCH = 8.0;
const int MOTOR_STEPS_PER_REV = 200;
const int MICROSTEPPING = 1;

bool activarInyectorFlag = false;
int stepDelay = 800;
bool homingDone = false;

Servo gripper1;
Servo gripper2;
Servo gripper3;
Servo gripper4;

// =====================================================
// ===============  COMUNICACIÓN CON ROBOT  ============
// =====================================================
String rxRobot = "";

// Envía un mensaje al robot
void enviarRobot(String msg) {
    Serial2.println(msg);
    Serial.print(">> Enviado al ROBOT: ");
    Serial.println(msg);
}

// Procesa comandos entrantes
void procesarMensajeRobot(String msg) {
    msg.trim();
    Serial.print("<< Robot dice: ");
    Serial.println(msg);

    // ===== ECU PLACED =====
    if (msg == "ECU_PLACED") {
        Serial.println(" ECU colocada → cerrando grippers...");
        cerrarGrippers();
        delay(500);
        enviarRobot("BOX_CLOSED");
    }

    // ===== WAIT_OK =====
    else if (msg == "WAIT_OK") {
        Serial.println(" Robot esperando confirmación...");
        rutinaCompleta();
        enviarRobot("CLEAN_DONE");
    }

    else if (msg == "POSE") {
        Serial.println(" Robot esperando confirmación...");
        girarServos24(170);
    }

    // ===== GET_ECU =====
    else if (msg == "GET_ECU") {
        Serial.println(" Robot viene a retirar la ECU...");
        abrirGrippers();
        delay(300);
        
    }

    else if (msg == "CONTRA") {
        Serial.println(" Robot esperando confirmación...");
        girarServos24(0);
    }
}
// Lee mensajes desde Serial2
void leerRobot() {
    while (Serial2.available()) {
        char c = Serial2.read();

        if (c == '\n') {
            procesarMensajeRobot(rxRobot);
            rxRobot = "";
        } 
        if (c == '\r') {
            procesarMensajeRobot(rxRobot);
            rxRobot = "";
        }
        else {
            rxRobot += c;
        }
    }
}
// =====================================================
// ================ FIN COMUNICACIÓN ====================
// =====================================================


void setup() {

    // --- Motores DC ---
    pinMode(ENA, OUTPUT);
    pinMode(IN1, OUTPUT);
    pinMode(IN2, OUTPUT);

    pinMode(ENB, OUTPUT);
    pinMode(IN3, OUTPUT);
    pinMode(IN4, OUTPUT);

    // --- Motores NEMA ---
    pinMode(X_STEP_PIN, OUTPUT);
    pinMode(X_DIR_PIN, OUTPUT);
    pinMode(X_ENABLE_PIN, OUTPUT);

    pinMode(Y_STEP_PIN, OUTPUT);
    pinMode(Y_DIR_PIN, OUTPUT);
    pinMode(Y_ENABLE_PIN, OUTPUT);

    // Endstops
    pinMode(Y_MIN_PIN, INPUT_PULLUP);
    pinMode(Y_MAX_PIN, INPUT_PULLUP);

    digitalWrite(X_ENABLE_PIN, LOW);
    digitalWrite(Y_ENABLE_PIN, LOW);

    // --- Servos ---
    gripper1.attach(SERVO1_PIN);
    gripper2.attach(SERVO2_PIN);
    gripper3.attach(SERVO3_PIN);
    gripper4.attach(SERVO4_PIN);

    Serial.begin(115200);
    Serial2.begin(115200);  // <<< NUEVO: COMUNICACIÓN CON ROBOT

    Serial.println("Iniciando sistema...");

    homingServos();
    hacerHoming();
    delay(500);

    moverAmbosMotores_mm(60, HIGH);
    delay(500);
    
    
}

void loop() {
    leerRobot();   // <<< NUEVO: escucha al robot TODO EL TIEMPO
    leerSimulacion();  // <<< NUEVO: comandos desde PC por USB
    //if (activarInyectorFlag) {
        //Inyector();    // ahora se ejecuta en el loop PRINCIPAL
    //}

}



// ================== FUNCIONES DE CONTROL ==================
void Inyector(){
    moverMotorB(150, true);
    activarInyector();
    delayMicroseconds(10000);
    desactivarInyector();
    delay(50);
}

// Motor A
void moverMotorA(int velocidad, bool adelante) {
    analogWrite(ENA, velocidad);
    digitalWrite(IN1, adelante ? HIGH : LOW);
    digitalWrite(IN2, adelante ? LOW : HIGH);
}

// Motor B
void moverMotorB(int velocidad, bool adelante) {
    analogWrite(ENB, velocidad);
    digitalWrite(IN3, adelante ? HIGH : LOW);
    digitalWrite(IN4, adelante ? LOW : HIGH);
}

// Inyector
void activarInyector() {
    digitalWrite(IN3, HIGH);
    digitalWrite(IN4, LOW);
}

void desactivarInyector() {
    digitalWrite(IN3, LOW);
    digitalWrite(IN4, HIGH);
}

void pararMotores() {
    analogWrite(ENA, 0);
    digitalWrite(IN1, LOW);
    digitalWrite(IN2, LOW);
}

// Grippers homing
void homingServos() {
    Serial.println("Homing de grippers...");
    gripper1.write(0);
    gripper3.write(0);
    delay(1000);
    gripper2.write(0);
    gripper4.write(170);
    delay(1000);
}

// Homing eje Y
void hacerHoming() {
    digitalWrite(X_DIR_PIN, LOW);
    digitalWrite(Y_DIR_PIN, LOW);
    Serial.println("Haciendo homing...");

    while (digitalRead(Y_MIN_PIN) == HIGH) {
        darPaso();
    }

    Serial.println("Homing completado");
}

// Conversión mm → pasos
long mmToSteps(float distancia_mm) {
    float vueltas = distancia_mm / LEADSCREW_PITCH;
    long pasos = vueltas * MOTOR_STEPS_PER_REV * MICROSTEPPING;
    return pasos;
}

// Movimiento NEMA
void moverAmbosMotores_mm(float distancia_mm, bool direccion) {
    long pasos = mmToSteps(distancia_mm);
    moverAmbosMotores(pasos, direccion);
}

void moverAmbosMotores(long pasos, bool direccion) {
    digitalWrite(X_DIR_PIN, direccion);
    digitalWrite(Y_DIR_PIN, direccion);

    for (long i = 0; i < pasos; i++) {

        if (digitalRead(Y_MAX_PIN) == LOW) {
            Serial.println("Y_MAX detectado, deteniendo motores");
            break;
        }

        darPaso();
    }
}

void darPaso() {
    digitalWrite(X_STEP_PIN, HIGH);
    digitalWrite(Y_STEP_PIN, HIGH);
    delayMicroseconds(stepDelay);

    digitalWrite(X_STEP_PIN, LOW);
    digitalWrite(Y_STEP_PIN, LOW);
    delayMicroseconds(stepDelay);
}

// Grippers
void cerrarGrippers() {
    Serial.println("Cerrando grippers...");
    gripper1.write(155);
    gripper3.write(155);
}

void abrirGrippers() {
    Serial.println("Abriendo grippers...");
    gripper1.write(0);
    gripper3.write(0);
}

// ======================================================
// ================   RUTINA COMPLETA   =================
// ======================================================

// Tiempo (ms) que dura la inyección
unsigned long tiempoInyeccion = 5000;   // <-- ajustalo

void rutinaCompleta() {

    Serial.println("=== INICIO RUTINA COMPLETA ===");

    //activarInyectorFlag = true;  // <<< ACTIVA

    // ---------- 1) Inyectores primera fase ----------
    Serial.println("Activando inyectores (fase 1)...");
    unsigned long inicio = millis();
    while (millis() - inicio < tiempoInyeccion) {
        Inyector(); 
    }
    analogWrite(ENB, 0);


    //activarInyectorFlag = false;   // <<< DESACTIVA
    moverAmbosMotores_mm(50, HIGH);

    // ---------- 2) Rotar servos 2 y 4 en conjunto ----------
    Serial.println("Girando servos 2 y 4...");
    girarServos24(170);   // Ángulo de giro → AJUSTAR SI QUERÉS
    delay(500);

    // ---------- 3) Segunda fase de inyectores ----------
    //activarInyectorFlag = true;  // <<< ACTIVA
    Serial.println("Activando inyectores (fase 2)...");
    inicio = millis();
    while (millis() - inicio < tiempoInyeccion) {
        Inyector(); 
    }
    analogWrite(ENB, 0);

    girarServos24(0);   // Ángulo de giro → AJUSTAR SI QUERÉS
    delay(500);

    // ---------- 4) Bajar hasta endstop MIN ----------
    Serial.println("Bajando hasta Y_MIN...");
    subirHastaMax();

    // ---------- 5) Activar motor A ----------
    Serial.println("Motor A funcionando...");
    moverMotorA(150, true);   // velocidad 150 adelante
    delay(4000);              // tiempo lavado → ajustar
    pararMotores();

    // ---------- 6) Subir hasta endstop MAX ----------
    Serial.println("Subiendo hasta Y_MAX...");
    bajarHastaMin();

    // ---------- 7) Posición segura ----------
    moverAmbosMotores_mm(60, HIGH);

    Serial.println("=== RUTINA COMPLETA FINALIZADA ===");
}

void girarServos24(int anguloFinal) {

    int s2 = gripper2.read();
    int s4 = gripper4.read();

    int paso2 = (anguloFinal > s2) ? 1 : -1;   // servo 2 normal
    int paso4 = -paso2;                       // servo 4 invertido

    int target4 = 170 - anguloFinal;          // siempre contrario

    while (s2 != anguloFinal || s4 != target4) {

        if (s2 != anguloFinal) {
            s2 += paso2;
            gripper2.write(s2);
        }

        if (s4 != target4) {
            s4 += paso4;
            gripper4.write(s4);
        }

        delay(10);
    }
}


void bajarHastaMin() {
    digitalWrite(Y_DIR_PIN, LOW);
    digitalWrite(X_DIR_PIN, LOW);

    while (digitalRead(Y_MIN_PIN) == HIGH) {
        darPaso();
    }
}

void subirHastaMax() {
    digitalWrite(Y_DIR_PIN, HIGH);
    digitalWrite(X_DIR_PIN, HIGH);

    while (digitalRead(Y_MAX_PIN) == HIGH) {
        darPaso();
    }
}




String rxSim = "";

void leerSimulacion() {
    while (Serial.available()) {
        char c = Serial.read();

        if (c == '\n') {
            procesarMensajeRobot(rxSim);  // <<< usamos la MISMA lógica
            rxSim = "";
        } else {
            rxSim += c;
        }
    }
}

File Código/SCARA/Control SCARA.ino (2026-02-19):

#include <AccelStepper.h>
#include <MultiStepper.h>
#include <Servo.h> 

// ============================
// 📌 Pines RAMPS y endstops
// ============================
#define X_STEP_PIN 54
#define X_DIR_PIN  55
#define X_EN_PIN   38
#define X_MIN_PIN   3

#define Y_STEP_PIN 60
#define Y_DIR_PIN  61
#define Y_EN_PIN   56
#define Y_MIN_PIN  14

#define Z_STEP_PIN 46
#define Z_DIR_PIN  48
#define Z_EN_PIN   62
#define Z_MIN_PIN   18

#define E0_STEP_PIN 26
#define E0_DIR_PIN  28
#define E0_EN_PIN   24
#define E0_MIN_PIN  19

#define GRIPPER_PIN 11   // pin digital de salida para el gripper

// ============================
// 📌 Límites de software (pasos) 
// ============================
#define J1_MIN -1204
#define J1_MAX  1204

#define J2_MIN -1354
#define J2_MAX  1354

#define Z_MIN  0
#define Z_MAX  4900
#define J6_MIN -10000
#define J6_MAX 10000

// ============================
// 📌 Home positions (valor que queremos que tenga cada eje cuando toca el endstop)
// ============================
#define J1_HOME_POS -1204
#define J2_HOME_POS  1354
#define Z_HOME_POS   0
#define J6_HOME_POS  0

// ============================
// 📌 Objetos motores
// ============================
AccelStepper stepperJ1(AccelStepper::DRIVER, X_STEP_PIN, X_DIR_PIN);
AccelStepper stepperJ2(AccelStepper::DRIVER, Y_STEP_PIN, Y_DIR_PIN);
AccelStepper stepperZ (AccelStepper::DRIVER, Z_STEP_PIN, Z_DIR_PIN);
AccelStepper stepperJ6(AccelStepper::DRIVER, E0_STEP_PIN, E0_DIR_PIN);
MultiStepper steppers; // lo dejamos por compatibilidad si lo querés usar después

Servo gripperServo;

// ============================
// 📌 Variables globales
// ============================
volatile bool stopRequested = false;
bool motorsEnabled = true;
bool gripperOpen = true;

bool movementActive = false; // <-- bandera: hay movimiento en curso?

#define SERVO_CLOSE_ANGLE -10  
#define SERVO_OPEN_ANGLE  180 

// Guardamos el estado "inverted" inicial (para poder restaurarlo)
bool j1_inverted = true;   // TU configuración original tenía J1 invertido
bool j2_inverted = false;  // J2 no estaba invertido originalmente (según tu código)

/* ---------------------------
   Función para energizar/desenergizar motores
   --------------------------- */
void enableMotors(bool state) {
  motorsEnabled = state;
  digitalWrite(X_EN_PIN, state ? LOW : HIGH);
  digitalWrite(Y_EN_PIN, state ? LOW : HIGH);
  digitalWrite(Z_EN_PIN, state ? LOW : HIGH);
  digitalWrite(E0_EN_PIN, state ? LOW : HIGH);

  if (state)
    Serial.println(" Motores ENERGIZADOS (enable on)");
  else
    Serial.println(" Motores DESENERGIZADOS (enable off)");
}

// ============================
// 📌 Setup
// ============================
void setup() {
  Serial.begin(115200);

  // Aplicamos la inversión inicial conocida (no la cambiamos aquí salvo que quieras)
  stepperJ1.setPinsInverted(j1_inverted, false, false);
  stepperJ2.setPinsInverted(j2_inverted, false, false);
  // otros ejes por defecto:
  stepperZ.setPinsInverted(false, false, false);
  stepperJ6.setPinsInverted(false, false, false);
  
  pinMode(X_EN_PIN, OUTPUT);
  pinMode(Y_EN_PIN, OUTPUT);
  pinMode(Z_EN_PIN, OUTPUT);
  pinMode(E0_EN_PIN, OUTPUT);

  pinMode(X_MIN_PIN, INPUT_PULLUP);
  pinMode(Y_MIN_PIN, INPUT_PULLUP);
  pinMode(Z_MIN_PIN, INPUT_PULLUP);
  pinMode(E0_MIN_PIN, INPUT_PULLUP);
  
  gripperServo.attach(GRIPPER_PIN); 
  gripperServo.write(SERVO_OPEN_ANGLE);
  gripperOpen = true;

  enableMotors(true); // activar motores al iniciar

  stepperJ1.setMaxSpeed(1000); stepperJ1.setAcceleration(200);
  stepperJ2.setMaxSpeed(1000); stepperJ2.setAcceleration(200);
  stepperZ.setMaxSpeed(800);   stepperZ.setAcceleration(150);
  stepperJ6.setMaxSpeed(1200); stepperJ6.setAcceleration(300);

  steppers.addStepper(stepperJ1);
  steppers.addStepper(stepperJ2);
  steppers.addStepper(stepperZ);
  steppers.addStepper(stepperJ6);

  Serial.println("Listo! Comandos:");
  Serial.println("home -> homing de todos los ejes (J6 no se mueve, se pone a 0)");
  Serial.println("moveJ J1 pasos vmax amax ...");
  Serial.println("moveL J1 target J2 target ...");
  Serial.println("enable on/off -> energiza o desenergiza motores");
  Serial.println("s o Enter vacío -> STOP global");
}

// ============================
// 📌 STOP global
// ============================
void stopAll() {
  stopRequested = true;

  stepperJ1.stop(); stepperJ2.stop(); stepperZ.stop(); stepperJ6.stop();

  stepperJ1.setCurrentPosition(stepperJ1.currentPosition());
  stepperJ2.setCurrentPosition(stepperJ2.currentPosition());
  stepperZ.setCurrentPosition(stepperZ.currentPosition());
  stepperJ6.setCurrentPosition(stepperJ6.currentPosition());

  long pos[4] = {stepperJ1.currentPosition(), stepperJ2.currentPosition(),
                 stepperZ.currentPosition(), stepperJ6.currentPosition()};
  steppers.moveTo(pos);

  movementActive = false; // evitar envíos al quedar en STOP
  Serial.println(" STOP GLOBAL ACTIVADO!");
}
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

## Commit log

2026-02-23 Create Arduino Mega 2560.PDF
2026-02-23 Create Poleas GT2 - Paso 2mm.pdf
2026-02-23 Create Perno de posición DIN 6325.pdf
2026-02-23 Create Perfil de aluminio 2040.pdf
2026-02-23 Create Filamento de impresión 3d PETG - Grilon3.pdf
2026-02-23 Create 625 - Rodamientos rígidos de bolas _ SKF.pdf
2026-02-23 Create 61805-2RS1 - Rodamientos rígidos de bolas _ SKF.pdf
